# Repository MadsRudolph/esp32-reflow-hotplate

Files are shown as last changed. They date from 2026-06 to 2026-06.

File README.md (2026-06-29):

# ESP32 SMD Reflow Hotplate

A from-scratch SMD reflow hotplate built around an ESP32, a 24 V DC PTC heater plate,
and a custom CNC-milled single-sided control board. Designed to reflow small/medium
SMD boards (up to ~100 × 100 mm) using PID-controlled reflow profiles.

> **Status:** in design. See [`docs/`](docs/) for the design spec.

## Why DC PTC (not mains)

The heater runs on **24 V DC**, switched by a power MOSFET — no mains voltage anywhere
in the build. Safer to build, debug, and leave running than an SSR + AC element.

## System overview

| Subsystem | Choice |
|---|---|
| Controller | ESP32 DevKit module |
| Heater | 24 V DC PTC aluminium plate, ~300 W (~13 A) |
| Power switch | IRFS4710 N-MOSFET, 12 V gate drive |
| Temp sensing | K-type thermocouple + MAX31855 (SPI) |
| Logic supply | 24 V → 5 V via LM2576 switching regulator |
| Gate-drive supply | 24 V → 12 V via LM7812 |
| UI | SSD1306 OLED + rotary encoder + start/stop button |
| Control board | Single-sided, through-hole, CNC-milled (Roland SRM-20) |
| Enclosure | 3D-printed (offset electronics box + metal-standoff plate mount) |

Most passives, the MOSFET, regulators, connectors and the encoder come from the **DTU
component shop** (through-hole lab stock). The ESP32 DevKit, MAX31855 thermocouple
module, OLED, 24 V PSU and the PTC heater plate are external modules/hardware.

## Repository layout

```
docs/            design spec, BOM, sourcing notes
hardware/kicad/   KiCad 10 project (schematic + single-sided board)
hardware/3d/      Blender sources + exported STL/STEP for printing
firmware/         ESP32 reflow-control firmware
```

## Production

- **PCB:** CNC-milled on a Roland SRM-20 (FR-1), single-sided, top nets as wire bridges.
  Design rules match the DTU laser/mill process: 1.0 mm trace / 0.8 mm clearance.
- **Enclosure:** FDM 3D print. The hot-plate mount uses **metal standoffs** with an air
  gap from the plastic — the plate reaches ~250 °C and must never touch printed parts.

## Safety

Mains-free by design, but reflow temperatures are dangerous. Planned protections:
hardware gate pulldown (power-off = heater-off), an inline thermal cutoff fuse on the
heater, a fused 24 V input, and firmware thermal-runaway / over-temperature watchdogs.

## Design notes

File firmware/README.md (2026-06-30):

# ESP32 Reflow Hotplate — Firmware

Embedded C firmware for the ESP32 reflow hotplate, written on ESP-IDF via PlatformIO.
Implements PID-controlled reflow profiles, a local OLED+encoder UI, and a WiFi LAN
dashboard for live monitoring and profile management.

## Quick start

```bash
# Run host-side Unity unit tests (no hardware needed)
cd firmware
pio test -e native

# Build firmware for the ESP32 (requires ESP-IDF toolchain download on first run)
pio run -e esp32dev

# Flash and monitor
pio run -e esp32dev -t upload
pio device monitor -e esp32dev
```

## Pin map

| Signal | GPIO  | Notes |
|---|---|---|
| HEATER_PWM | 25 | Time-proportional slow PWM (~1–2 s window), fail-safe low |
| TC_SCK | 18 | MAX31855 SPI clock |
| TC_SO | 19 | MAX31855 SPI MISO (read-only; no MOSI) |
| TC_CS | 5 | MAX31855 chip select |
| OLED_SDA | 21 | SSD1306 I2C data |
| OLED_SCL | 22 | SSD1306 I2C clock |
| ENC_A | 32 | Rotary encoder channel A (PCNT) |
| ENC_B | 33 | Rotary encoder channel B (PCNT) |
| ENC_SW | 27 | Encoder push-switch (GPIO ISR) |
| BTN_START | 26 | Start/stop button |
| LED_STATUS | 4 | Status LED |
| FAN_PWM | 13 | 5 V cooling fan, split-range PID (low-side N-MOSFET); **not yet on the fabricated board — pending board revision** |

## Architecture

```
firmware/
  platformio.ini        env:esp32dev (espidf) + env:native (gcc + Unity)
  partitions.csv        app + nvs (profiles)
  src/
    core/   Pure C — no ESP-IDF deps; covered by native Unity tests
    hal/    ESP-IDF C drivers (bench-verified)
    ui/     OLED screens + encoder navigation
    net/    WiFi station + HTTP server + WebSocket dashboard
    app/main.c
  lib/core/             Pure-C library include path (for native env)
  test/test_smoke/      Smoke test: verifies toolchain and Unity work
```

## Safety

Hard over-temp cutoff at 260 °C (above SAC305 reflow peak, below damage threshold).
Runs are started and aborted **locally only** — the web dashboard is monitoring/profiles only.
WiFi credentials live in gitignored `src/net/wifi_config.h`.

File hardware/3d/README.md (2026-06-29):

# ESP32 Reflow Hotplate — 3D Enclosure

Parametric 3-part enclosure for the ESP32 reflow hotplate: a **plate frame** that
holds the ~250 °C heater plate on ceramic standoffs over an open air gap, an
**electronics box** that carries the 104×104 mm control board flat, and a **top
control panel** that closes the box and exposes the encoder, button, LED and OLED.

The whole model is parametric. Everything geometry-relevant lives in
[`params.py`](params.py); change a value there (e.g. the real plate dimensions)
and re-run [`build_all.py`](build_all.py) to regenerate all parts, the assembled
`enclosure.blend`, and the STL set.

---

## Files

| File | Role |
|---|---|
| `stl/plate_frame.stl`, `stl/box.stl`, `stl/panel.stl` | **Print these.** One STL per part. |
| `enclosure.blend` | Assembled scene (box at origin, panel on top, plate frame beside). Parametric source-of-truth render. |
| `params.py` | All dimensions/parameters. **Edit here**, then re-run. |
| `build_common.py` | Blender helpers (booleans, manifold check, STL export, verify). |
| `build_plate_frame.py`, `build_box.py`, `build_panel.py` | Per-part parametric builders (`build()` each). |
| `build_all.py` | Assembles all three, runs the box↔panel interference check, exports STL, saves `.blend`. |

**STEP export** is intentionally out of scope — Blender has no native STEP
exporter. If a STEP/CAD hand-off is needed, it is an optional FreeCAD follow-up
(import the STL or rebuild from `params.py`). The `.blend` + `build_*.py` are the
parametric source.

### Regenerating everything

In a running Blender (5.x) with the MCP/console:

```python
exec(open(r".../hardware/3d/build_all.py").read())
r = build_all()
print(r)
# all three parts -> manifold_ok True, fits_bed True
# interference.box_panel ~ 0  (box walls do NOT pass through the panel)
# 3 STL written to stl/, enclosure.blend saved
```

The build asserts each part is **manifold/watertight** (`nonmanifold == 0`) — a
non-watertight STL is never exported. The box↔panel interference is measured by a
temporary boolean INTERSECT whose volume must be ≈ 0 (only the rim/screw bosses
touch the panel underside; the walls must not intersect the panel body).

---

## Print settings

- **Material:** PETG (chosen for higher glass-transition temp and toughness near
  the warm enclosure; the plate itself is held off all plastic — see thermal note).
- **Walls / perimeters:** **≥ 3** (the screw bosses and standoff bosses rely on
  solid walls for thread/insert retention).
- **Infill:** **~25–40%** (gyroid or grid). Toward the higher end for the box if
  you want extra rigidity under the board + panel.
- **Layer height:** 0.2 mm is fine for all parts.
- **Supports:** enable for overhangs — specifically the **box terminal opening**
  (the rectangular J1/J2 cut-out in the −Y wall) and any **panel cut-out
  overhang**. The vent slots and bores are bridgeable but inspect them.
- **Orientation:** print box and plate frame floor-down (open side up); print the
  panel flat, control face up.

---

## Heat-set inserts

- **Type:** M3 brass heat-set inserts.
- **Boss bore:** **Ø 4.0 mm** (`insert_bore_d`), ~6 mm deep (`insert_bore_depth`)
  in each of the 4 box top-rim bosses.
- **Install:** push each insert in with a **soldering iron** set to ~200–230 °C —
  let the brass melt into the bore until flush with the boss top, then back the
  iron out straight so the insert stays square.

---

## Hardware BOM

| Qty | Item | Notes |
|-----|---|---|
| 4 | **M3 ceramic standoffs — FEMALE-THREADED** | **CRITICAL:** the plate-frame bosses are **blind** (solid foot below, no through-clearance for a bottom nut). The standoff must be **female-threaded** and **seat on the boss top**; the M3 screw threads **UP into the plate** from above. A plain spacer that needs a nut underneath the frame **will NOT fit.** |
| 4 | M3 steel screws (for the plate) | Thread up through the plate into the female ceramic standoffs. Length to suit plate thickness + a few mm of engagement. |
| 4 | M3 brass heat-set inserts | Pressed into the box top-rim bosses (Ø4.0 bore). |
| 4 | M3 screws (box↔panel) | Pass down through the panel clearance holes into the box-rim inserts. |
| 4 | Rubber feet | Stick-on, under the box (and/or plate frame). |
| 0 | Board screws | **None needed.** The control board has no mounting holes — it **rests on the box's 4 corner posts** and is captured from above by the top panel. |

---

## Assembly order

1. **Press the heat-set inserts** into the **box top-rim bosses** (4×, Ø4.0 bore)
   with a soldering iron; let them seat flush and square.
2. **Bolt the plate** to the **plate frame** on the **ceramic standoffs**: seat a
   female-threaded ceramic standoff on each boss, then run an M3 steel screw
   **up** from the standoff into the plate.
3. **Drop the control board** onto the box's **4 corner support posts** (no
   screws — it simply rests on the posts, lifted off the floor for the bottom
   lead tails).
4. **Wire the OLED module to J4** and seat it under the **panel's OLED window**.
5. **Screw the top control panel down** onto the box (4× M3 into the heat-set
   inserts). This captures the board and aligns the encoder / button / LED / OLED
   with their panel cut-outs.
6. **Stick the rubber feet** on the underside.
7. **Wire the power side** through the **terminal opening** in the box −Y wall:
   24 V-in (**J1**) and the heater output (**J2**), plus the **two thick power
   wire-bridges** and the **signal jumpers** per the PCB `MILL_NOTES`.

---

## Thermal safety

- The heater plate runs at roughly **~250 °C**. **Ceramic standoffs** plus the
  **22 mm air gap** (`standoff_h`) keep that plate off **all** plastic — nothing
  printed ever touches the hot plate.
- The **electronics box is physically offset** from the plate (separate part,
  placed beside it), keeping the control board out of the heat plume.
- This is a conservative starting point. **Re-verify** the standoff height / air
  gap and the box offset **once the real plate's sustained surface temperature is
  known** — if the production plate runs hotter or the plume is wider than
  assumed, increase `standoff_h` (and/or the box offset) in `params.py` and
  re-run `build_all.py`.

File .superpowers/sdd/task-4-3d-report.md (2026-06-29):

# Task 4 — Top control panel (`build_panel.py`) report

## Affine (board frame → panel frame)
The board is centred in the box, so the board centre `(pcb_x/2, pcb_y/2)` maps to
the panel centre `(0,0)`. placement.json positions are in board frame (origin at
board lower-left). The map is a pure translation:

```
panel_x = board_x - pcb_x/2   (= board_x - 52.0)
panel_y = board_y - pcb_y/2   (= board_y - 52.0)
```

Checks: SW1 (25.6,11.1)→(-26.4,-40.9); SW2 (41.9,7.8)→(-10.1,-44.2);
D1 (52.7,7.2)→(0.7,-44.8); J4 (5.8,9.6)→(-46.2,-42.4).

## What was built
PETG plate `box_x × box_y × panel_t` = 113×113×3, top face up (z=0..3). One
manifold object `panel`. Cuts (all booleaned through):
- Encoder shaft Ø7.5 (encoder_shaft_d) at SW1
- Push-button Ø12.5 (button_d) at SW2
- LED Ø5.5 (led_d) at D1
- OLED window 26×15 (oled_win_x × oled_win_y, X×Y) at J4
- Vent slots (4 × 2.5×18, pitch 6) over the regulator zone: centred at the
  midpoint of U2/U3 mapped through the affine (panel x≈-1.55, y≈-21.7), i.e. the
  power corner (placement.json `_doc`: lower-left) regulator/MOSFET band.
- 4 × Ø3.4 M3 clearance holes at `top_insert_centers()` = (±52.5, ±52.5).

## Verification (real Blender output)
```
verify = {"nonmanifold": 0, "bbox": (113, 113, 3),
          "manifold_ok": True, "fits_bed": True}
cut_centers = {"SW1": (-26.4,-40.9), "SW2": (-10.1,-44.2),
               "D1": (0.7,-44.8), "J4": (-46.2,-42.4)}
MATES box rim = True
hole_centers       = [(-52.5,-52.5),(-52.5,52.5),(52.5,-52.5),(52.5,52.5)]
top_insert_centers = [(-52.5,-52.5),(-52.5,52.5),(52.5,-52.5),(52.5,52.5)]
```
Single watertight solid. STL written: `hardware/3d/stl/panel.stl`.

## Files changed
- `hardware/3d/build_panel.py` (new)
- `hardware/3d/stl/panel.stl` (new)

## Concerns
- OLED window orientation assumed `oled_win_x` along panel X, `oled_win_y` along
  panel Y (J4 rotation in placement.json is 0). If the physical OLED module is
  rotated, the window may need swapping — low risk given the 0° placement.
- Vent slots are a small decorative/airflow row over the regulator zone; exact
  count/pitch chosen for manifold cleanliness, not validated against a thermal
  model.

## Review fix (vents from JSON + OLED rot)

### What changed
1. **Vent anchors from placement.json** (`build_panel.py` lines ~111-125): removed
   the two hardcoded board-x literals `42.5` (U2) and `58.4` (U3). The build
   function now reads `placement.json` keys `U2` and `U3` at runtime using
   `_pl.get("U2", [42.5, 30.3, 0])` / `_pl.get("U3", [58.4, 30.3, 0])`, maps
   them through the existing `_affine()` call, and computes `vent_cx`/`vent_cy`
   from those results. Fallback defaults (the original literals) are used only if
   a key is absent — no crash.

2. **J4 rotation assert** (`build_panel.py` before the OLED boolean): added
   `assert pl_j4_rot == 0` with a message explaining how to handle 90°/270°
   rotation (swap `oled_win_x`/`oled_win_y`). This will surface immediately if
   the board is respun with a rotated OLED header.

### JSON-derived vent anchors (from real Blender run)
| Component | Board frame (mm) | Panel frame (mm) |
|---|---|---|
| U2 | [42.5, 30.3] | (-9.5, -21.7) |
| U3 | [58.4, 30.3] | (6.4, -21.7) |
| vent_cx | — | -1.55 |
| vent_cy | — | -21.7 |

### Verification output (real Blender output)
```
verify = {'nonmanifold': 0, 'bbox': (113.0, 113.0, 3.0), 'manifold_ok': True, 'fits_bed': True}
cut_centers = {'SW1': (-26.4, -40.9), 'SW2': (-10.1, -44.2), 'D1': (0.7, -44.8), 'J4': (-46.2, -42.4)}
MATES = True
U2 board=[42.5, 30.3] -> panel=(-9.5, -21.7)
U3 board=[58.4, 30.3] -> panel=(6.4, -21.7)
vent_cx=-1.55, vent_cy=-21.7
STL exported OK
```
Still manifold; cut_centers unchanged; MATES True; STL re-exported.

## OLED window overhang fix

### Root cause
The OLED window (J4) was centred at panel (−46.2, −42.4), derived from the J4
board footprint via the affine transform. With `oled_win_x = 26 mm`, the window's
left edge fell at `−46.2 − 13.0 = −59.2 mm`, overhanging the panel half-width of
56.5 mm by **2.7 mm** — an open-sided notch instead of an enclosed window.

### Why the fix is a free design choice
The SSD1306 OLED module connects to J4 via a short 4-wire cable (JST), not by
sitting directly above the connector. The panel window position is therefore
**independent of J4's board coordinate** and can go anywhere on the panel
consistent with the geometry constraints.

### New OLED position
`_OLED_PANEL_X = −25.0 mm`, `_OLED_PANEL_Y = 20.0 mm` — upper-left quadrant of
the panel, clear of the SW1/SW2/D1 control row (which sits at y ≈ −41 to −45 mm).

Window edge coordinates (26×15 mm window, half-extents 13 and 7.5 mm):

| Edge | Value (mm) | Panel limit (mm) | Margin (mm) |
|---|---|---|---|
| Left | −38.0 | −53.5 | +15.5 |
| Right  | −12.0 | +53.5 | +65.5 |
| Bottom | +12.5 | −53.5 | +66.0 |
| Top | +27.5 | +53.5 | +26.0 |

All four edges are well within ±53.5 mm. Nearest screw hole is at (−52.5, 52.5)
Ø3.4 mm; gap from screw edge to window edge ≥ 12.8 mm (requirement: ≥ 2 mm).

### The guard: `_assert_inside_outline()`
Added to `build_panel.py`. Checks every cut before the booleans run:
- **Control holes** (SW1 encoder, SW2 button, D1 LED): centre ± radius within
  ±(box/2 − 3 mm) = ±53.5 mm.
- **OLED window**: centre ± half-extent within ±53.5 mm.
- **Screw holes**: centre ± radius within ±(box/2 − 1 mm) = ±55.5 mm (corner
  holes are by design near panel corners within the wall zone; 1 mm physical
  margin is appropriate for them).

Called in `build()` immediately after `cut_centers()`. Raises `AssertionError`
with an explicit message identifying the offending cut and edge coordinate.

### Guard fires on the bad position
Temporarily overriding the OLED center to the original bad position (−46.2, −42.4)
triggers:
```
AssertionError: _assert_inside_outline: OLED window left edge -59.200 < -53.500
```
The guard has teeth — it catches the open-sided-notch class of bug that the
manifold check misses (a manifold solid can still have open-sided slots if the
panel outline itself is intact but a cut overhangs an edge).

### Verification output (real Blender run after fix)
```
verify = {'nonmanifold': 0, 'bbox': (113, 113, 3), 'manifold_ok': True, 'fits_bed': True}
cut_centers = {'SW1': (-26.4, -40.9), 'SW2': (-10.1, -44.2), 'D1': (0.7, -44.8), 'J4': (-25.0, 20.0)}
MATES = True
OLED edges: left=-38.0, right=-12.0, bottom=12.5, top=27.5  (all within ±53.5)
_assert_inside_outline: PASSED on new position
_assert_inside_outline: FIRES on bad position (-46.2, -42.4) with message above
STL re-exported: hardware/3d/stl/panel.stl
```
SW1/SW2/D1 centres unchanged. MATES True. Manifold. OLED fully enclosed.

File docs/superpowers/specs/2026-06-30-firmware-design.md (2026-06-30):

# ESP32 Reflow Hotplate — Firmware Design Spec

**Date:** 2026-06-30
**Status:** Approved (brainstorming complete; ready for implementation planning)
**Parent project:** ESP32 SMD Reflow Hotplate (see `2026-06-29-esp32-reflow-hotplate-design.md` §6)

## 1. Goal

Firmware for the ESP32 reflow hotplate: read the plate temperature, run a PID-controlled
reflow profile to drive the 13 A heater safely, present a local OLED + encoder UI, and
serve a WiFi web dashboard on the LAN for live monitoring and profile management.
Written in **embedded C on ESP-IDF** (PlatformIO), with the safety-critical control logic
isolated as pure C and unit-tested natively.

### Non-goals (YAGNI)
- No remote start/abort of reflow runs — runs are started/aborted **locally only** (a 13 A
  heater must not be started unattended over the network).
- No cloud/internet dependency — the dashboard is served by the device on the LAN.
- No OTA firmware update in v1.
- No multi-plate / multi-zone control.

## 2. Key decisions (from brainstorming)

| Decision | Choice | Reason |
|---|---|---|
| Language / framework | **Embedded C on ESP-IDF** (PlatformIO `framework = espidf`) | Pure C, no C++/Arduino; native C driver APIs + FreeRTOS |
| Control loop | **PID**, position form, anti-windup, derivative-on-measurement; fixed conservative default gains | Reliable reflow tracking; tune once per plate |
| Heater output | **Time-proportional control** (slow ~1–2 s PWM window on GPIO25), fail-safe low | Standard for thermal/heater control |
| Cooling / fan | **5 V fan on GPIO13**, driven as the cooling half of a **bipolar split-range PID** (heater vs fan, deadband) | Active cooling on the down-ramp → more accurate curves; needs a board revision |
| Testability | `core/` is pure C (no ESP-IDF deps) → **PlatformIO `native` Unity tests**; HAL bench-verified | Fast TDD for the safety-critical logic |
| Profiles | **Editable, persisted to NVS** (`nvs_flash`); seeded with leaded Sn63/Pb37 + lead-free SAC305 | Tweak without reflash; managed from OLED and web |
| Local UI | SSD1306 OLED + rotary encoder + start/stop button | Standalone operation |
| Network | **WiFi station + `esp_http_server`**; embedded SPA dashboard; WebSocket live telemetry; REST profile CRUD | LAN monitoring + profile management |
| Dashboard scope | **Monitor + manage profiles**; runs start/abort LOCAL only | Fire-safety for a 13 A heater |
| Safety ceiling | Hard over-temp cutoff **260 °C** | Above SAC305 peak, below damage |
| WiFi credentials | Gitignored `wifi_config.h` (or NVS) | Simple; never commit creds |

## 3. Architecture (layered for isolation + testability)

```
firmware/                         PlatformIO project (framework = espidf)
  platformio.ini                  env:esp32dev (espidf) + env:native (gcc + Unity)
  partitions.csv                  app + nvs (profiles)
  src/
    core/      PURE C — NO ESP-IDF/Arduino deps → native Unity tests
      pid.c/.h        position PID, anti-windup clamp, derivative-on-measurement (BIPOLAR output)
      actuator.c/.h   split-range: bipolar effort → (heater_duty, fan_duty) with a deadband
      profile.c/.h    profile model (stages) + setpoint-vs-time interpolation + validation
      reflow.c/.h     run state machine (idle→preheat→soak→reflow→cool→done / fault)
      safety.c/.h     watchdog: pure verdict from (temp, heater_duty, dt, flags)
      settings.c/.h   profile store; storage behind a struct-of-fn-pointers (fake in tests)
    hal/       ESP-IDF C drivers (bench-verified, not native-tested)
      tc_max31855.c   driver/spi_master: read 32-bit word, parse temp + fault bits
      oled_ssd1306.c  driver/i2c_master: minimal text/line/bar driver
      heater.c        time-proportional slow-PWM on GPIO25; fail-safe low
      fan.c           5 V cooling fan PWM (LEDC) on GPIO13; off on init/abort/fault
      encoder.c       PCNT peripheral (A/B) + GPIO ISR for switch
      button.c, led.c GPIO
    ui/ui.c           OLED screens + encoder navigation (depends on core + hal)
    net/       WiFi + web (independent of the control loop)
      wifi.c          esp_wifi station; creds from gitignored wifi_config.h
      httpd.c         esp_http_server: serves SPA + REST + WebSocket
      api.c           endpoints; reads run snapshot, writes profiles via settings.c
      www/            dashboard SPA (HTML/CSS/JS), embedded into flash (EMBED_FILES)
    app/main.c        app_main: nvs init, HAL init, wifi/httpd start, control FreeRTOS task
  test/native/        Unity tests for core/*
  README.md           pinout, build/flash, bench-verification steps
```

### 3.1 Pin map (from `hardware/kicad/net_contract.json`)
`HEATER_PWM=GPIO25, TC_SCK=GPIO18, TC_SO=GPIO19, TC_CS=GPIO5, OLED_SDA=GPIO21,
OLED_SCL=GPIO22, ENC_A=GPIO32, ENC_B=GPIO33, ENC_SW=GPIO27, BTN_START=GPIO26,
LED_STATUS=GPIO4, FAN_PWM=GPIO13`. SPI is read-only (no MOSI); MAX31855 is the only SPI
device. **FAN_PWM (GPIO13)** drives a 5 V cooling fan — added 2026-06-30; it is NOT on the
fabricated board yet and needs a board revision (see §12).

## 4. Control core (`core/`)

- **`pid`** — position-form PID; **bipolar output −100…+100 %** (positive = heat demand,
  negative = cool demand). Anti-windup (conditional integration on either rail); derivative
  on the measurement (not the error) to avoid a setpoint kick at stage boundaries; NaN/Inf
  output → fail-safe minimum. Conservative default `Kp/Ki/Kd` in config; documented tuning.
- **`actuator` (split-range)** — maps the bipolar PID effort to two non-overlapping outputs
  with a deadband: `effort > +deadband` → `heater_duty = effort, fan_duty = 0`;
  `effort < −deadband` → `fan_duty = |effort|, heater_duty = 0`; inside the deadband both
  off. **Heating and cooling are never commanded at once.** Pure function, fully unit-tested.
- **`profile`** — a profile is an ordered list of stages `{name, target_c, duration_s}`
  for preheat → soak → reflow(peak) → cool. `profile_setpoint(profile, elapsed_s)` returns
  the interpolated target. `profile_validate()` enforces: stage count/limits, monotonic
  time, each `target_c ≤ SAFETY_CEILING`, sane durations — used by both OLED edits and
  web uploads.
- **`reflow`** — the run state machine: `IDLE → PREHEAT → SOAK → REFLOW → COOL → DONE`,
  plus `FAULT`. Advances stages by the profile; computes the live setpoint; consumes the
  `safety` verdict to abort. Publishes a run snapshot.
- **`safety`** — pure function evaluated every tick; forces heater + fan OFF + `FAULT` on:
  over-temp (`≥ 260 °C`), thermal runaway (**heater_duty** high but temp not rising ≥ ~2 °C /
  20 s — evaluated on heater duty only, so active fan cooling never trips it), thermocouple
  fault (open/short/NaN/out-of-band), sensor stall (no fresh reading in timeout). Faults
  latch until acknowledged.
- **`settings`** — profile CRUD over an injected `storage_if` (struct of read/write fn
  pointers). On-device it binds to NVS; in native tests, to an in-memory fake. Seeds the
  two default profiles on first boot.

## 5. HAL (`hal/`, ESP-IDF C)
Thin wrappers, no business logic: `tc_max31855` (SPI word → °C + fault), `oled_ssd1306`
(I²C text/line/bar), `heater` (time-proportional slow-PWM, fail-safe low on init/abort),
`fan` (5 V cooling-fan PWM via LEDC on GPIO13, off on init/abort/fault), `encoder` (PCNT
quadrature + GPIO ISR switch), `button`, `led`. Verified on the bench; the steps are
documented in `firmware/README.md`.

## 6. Local UI (`ui/`)
```
IDLE/SELECT → rotate: pick profile → press: MENU {RUN, EDIT}
EDIT  → pick stage field (temp/time), adjust, save → NVS
RUN   → live: target vs actual °C, stage, elapsed, duty bar  (button aborts)
DONE/COOLDOWN → "remove board, cooling" until cool → IDLE
FAULT → reason; button acknowledges → IDLE
```
Encoder rotate = navigate/adjust, encoder press = select, dedicated button = start/abort.

## 7. Network dashboard (`net/`)
- **`wifi`** — station mode; joins the LAN using creds from a gitignored `wifi_config.h`
  (SSID/pass) — never committed. WiFi/web failure must NOT affect the control loop.
- **`httpd`/`api`** — `esp_http_server`:
  - `GET /` → embedded SPA (HTML/CSS/JS in flash; no internet dependency).
  - `GET /ws` → WebSocket pushing live telemetry ~2–4×/s: `t, target, actual, duty, stage,
    state, fault`.
  - `GET /api/status` → snapshot (first paint / non-WS clients).
  - `GET /api/profiles`, `GET /api/profiles/{id}` → read.
  - `POST /api/profiles`, `PUT /{id}`, `DELETE /{id}` → create/edit/upload/delete a profile
    (JSON), `profile_validate()`d, then persisted to NVS via `settings`.
- **Dashboard SPA** — live temperature chart (target vs actual) + stage/duty/state/fault
  tiles; a profile manager (list → edit form → save/upload/delete). Self-contained.
- **Concurrency / safety boundary** — the control FreeRTOS task owns the heater and run
  state and publishes a snapshot (mutex/atomic). The httpd task only *reads* the snapshot
  and *enqueues validated profile writes*; it can never command the heater or start a run.

## 8. Telemetry
During a run, also stream one CSV line per tick over USB serial (`t,target,actual,duty,
stage`) for plotting and PID tuning.

## 9. Concurrency model (FreeRTOS)
- **Control task** (fixed tick, e.g. 250 ms, high priority): TC read → `safety` →
  `pid` (bipolar) → `actuator` (split-range) → `heater` + `fan` duties → publish snapshot →
  `ui` update + serial CSV. Owns all heater AND fan control.
- **httpd task** (esp_http_server): serves dashboard, reads the published snapshot, pushes
  WS telemetry, handles profile CRUD (enqueues writes consumed by the control/settings side).
- **wifi** events handled async. The control + safety loop is independent of WiFi/web state.

## 10. Testing (PlatformIO `native` env, Unity)
- `pid`: step response, anti-windup saturation, no derivative kick at setpoint change.
- `actuator`: positive effort → heater only; negative → fan only; deadband → both off;
  never heater+fan simultaneously; clamps to valid duty ranges.
- `profile`: interpolation across stage boundaries; `profile_validate` accepts good /
  rejects bad (non-monotonic, over-ceiling, zero-duration); defaults correct.
- `reflow`: full state-machine path + abort + fault transitions.
- `safety`: each trip fires and forces heater off; **fakes feed adversarial inputs** —
  the regression net for a 13 A heater.
- `settings`: CRUD + persist + reload through the in-memory `storage_if` fake.
HAL, UI, and net are bench/integration-verified (documented in README), not native-tested.

## 11. Repository layout
```
firmware/   the PlatformIO ESP-IDF project above (src/, test/native/, platformio.ini, README.md)
```

## 12. Risks & open items
- **PID tuning:** ship conservative gains; first-run tuning expected (serial CSV + dashboard
  chart aid this). Re-tune for the real plate's thermal mass.
- **OLED/encoder C drivers:** minimal hand-rolled drivers (no Adafruit) — budget bench time.
- **WiFi creds:** gitignored `wifi_config.h`; document the template. Provisioning portal is
  a later option.
- **Heater fail-safe:** `heater` must drive GPIO25 low on init, abort, fault, and task crash;
  this complements the hardware boot-safe gate. Covered explicitly in tests/bench checks.
- **Fan board revision (hardware):** the 5 V cooling fan on `FAN_PWM`=GPIO13 is NOT on the
  fabricated board — it needs a board revision: a logic-level N-MOSFET (2N7000/BS170) low-side
  switching the fan off `+5V`, a flyback diode, and a 2-pin fan connector (the `FANDRV`
  sub-circuit in `net_contract.json`). Folds into the next board spin (production files already
  stale from the PCB re-placement). The firmware `fan` HAL must default the GPIO low/off.
- **Flash size for the embedded SPA:** keep the dashboard self-contained and small; verify it
  fits the app partition.

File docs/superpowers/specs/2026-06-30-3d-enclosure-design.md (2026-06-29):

# ESP32 Reflow Hotplate — 3D Enclosure Design Spec

**Date:** 2026-06-30
**Status:** Approved (brainstorming complete; ready for implementation planning)
**Parent project:** ESP32 SMD Reflow Hotplate (see `2026-06-29-esp32-reflow-hotplate-design.md` §7)

## 1. Goal

Design the 3D-printable enclosure for the reflow hotplate: hold the ~250 °C heater plate
safely above the electronics, house the CNC-milled control board, and present the OLED +
encoder + button + LED on a front panel. Deliverables: parametric Blender source + exported
STL (print) and STEP (CAD interchange) for each part.

### Non-goals (YAGNI)
- No active cooling (no fan) — passive vents only.
- No latching/hinged lid — the lid is screwed.
- No enclosure for the 24 V PSU (external brick stays separate).

## 2. Key decisions (from brainstorming)

| Decision | Choice | Reason |
|---|---|---|
| Heater plate | Parametric around 100×100 mm aluminium PTC, 4× corner M3 holes | No specific plate yet; adapt later by changing variables |
| Layout | Electronics box **offset to the side** of the plate | Keeps all plastic out of the rising heat plume — safest |
| Thermal isolation | Plate on **ceramic standoffs** (~20–25 mm) + open air gap | Ceramic conducts little heat → PETG base stays well below its ~80 °C Tg |
| Fastening | **M3 brass heat-set inserts** in PETG for the box↔top-panel joint; plate uses steel M3 screws through **female-threaded** ceramic standoffs; the control board **rests on corner posts** (it has no mounting holes) | Durable, re-openable threads; the board needs no holes |
| Parts | **3 printed: plate frame, electronics box, top control panel** | The board's controls point up, so one TOP panel both closes the box and carries the cut-outs (it is also the lid) |
| Material | PETG (base/box); hot zone is all metal/ceramic | Better heat tolerance than PLA; nothing plastic touches the plate |
| Modeling | Blender (MCP), parametric variables | **STL + the parametric `.blend`/`.py`** (Blender has no native STEP export; STEP is an optional FreeCAD follow-up) |

> **Design correction (2026-06-30, mid-build):** the original 4-part plan (vertical front panel + separate lid) was geometrically wrong — the 104×104 board is larger than the first box envelope, has no mounting holes, and its through-hole controls (SW1/SW2/D1) point *up*, so they must come through a panel parallel and above the board. Corrected to the 3-part design below.

## 3. Architecture (3 printed parts + hardware)

### 3.1 Plate frame
PETG base/ring that the heater plate bolts onto via **4 female-threaded ceramic standoffs** (the
standoff seats on the frame's blind boss; a steel M3 screw threads UP through the standoff into
the plate's corner hole — NOT down through the frame). The standoffs raise the plate ~22 mm with
an **open air gap** beneath, and the ceramic is the only thermal path to the printed part —
breaking conduction. Footprint and hole pattern are parametric to the plate. A routed channel
carries the plate's heater wires toward the electronics side. Feet under the corners.

### 3.2 Electronics box
Sits **beside** the plate frame, out of the heat plume, sized (~113×113 mm) to hold the **104×104
control board flat**. The board **rests on 4 corner support posts** (lifted off the floor for the
bottom lead tails) — it has no mounting holes, so it is captured from above by the top panel, not
bolted. Features:
- Vent slots above the LM2575 / LM7812 regulators and the Q1 (IRFS4710) TO-220 heatsink.
- Side openings for the 24 V-in (J1) and heater-out (J2) screw terminals.
- **Heat-set inserts on the top rim** to receive the top control panel.

### 3.3 Top control panel (also the lid)
A PETG plate that **closes the box top** and carries the controls — the user looks down on it.
Cut-outs **aligned to the control board's on-board component positions** (from
`hardware/kicad/placement.json`, board centred under the panel): the rotary encoder (SW1) shaft,
the start button (SW2), the status LED (D1), and an **OLED window** for the J4-connected SSD1306
module. Vent slots over the heat-generating zone. Bolts down into the box top-rim heat-set inserts
with M3 screws.

### 3.4 Hardware (bring-your-own)
- Plate: 4× **female-threaded** ceramic standoffs + 4× steel M3 screws.
- Box↔panel: M3 brass heat-set inserts + M3 screws.
- 4× rubber feet. (The control board needs no screws — it rests on the box posts.)

## 4. Thermal safety rationale
The ~250 °C plate never contacts printed plastic: it stands on ceramic over an air gap, and the
electronics box is laterally offset from the plume. PETG (Tg ~80 °C) is used for structure; the
ceramic standoffs + air gap keep the frame's screw bosses far below softening even on sustained
runs. (The plate-mount geometry should be sanity-checked against the real plate's wattage during
implementation.)

## 5. Parametric variables (Blender)
Single source of truth so the model adapts to the real plate and board:
- `plate_x`, `plate_y`, `plate_thickness` (default 100, 100, ~5 mm)
- `plate_hole_inset`, `plate_hole_dia` (corner M3 pattern)
- `standoff_height` (air gap, default ~22 mm), `standoff_dia`
- `insert_dia_m3`, `insert_depth` (heat-set boss geometry)
- `panel_cutouts`: SW1/SW2/D1/OLED positions + sizes, driven by the board's
  `placement.json` coordinates
- `wall_thickness`, `bed_max` (220 mm) for part-splitting checks

## 6. Repository layout
```
hardware/3d/
  enclosure.blend           Blender source (parametric)
  stl/                      exported STL per part (print)
  step/                     exported STEP per part (CAD)
  README.md                 print settings, insert sizes, assembly + hardware BOM
```

## 7. Verification (the 3D equivalent of tests)
- Each part exports a manifold (watertight) STL — checked in Blender (no non-manifold edges / holes).
- Fit checks against parameters: plate-hole pattern matches `plate_*`; panel cutout coords match
  `placement.json`; heat-set boss bores match the chosen insert (e.g. M3 → ~4.0 mm).
- Every part's bounding box ≤ 220×220 mm (bed); flag any that needs splitting.
- Wall thickness ≥ a printable minimum; standoff/air-gap height ≥ the thermal-safety value.
- Assembly dry-run in Blender: parts mate without interference (box ↔ panel ↔ lid; plate frame
  standoff spacing).

## 8. Risks & open items
- **Plate spec (still the key input):** exact plate dimensions/holes/thickness and the real wire
  exit must be confirmed before the final print; the parametric model makes this a variable change.
- **Standoff height vs. heat:** ~22 mm air gap assumed safe; re-check once the plate's sustained
  surface/edge temperature is known.
- **Panel ↔ board alignment:** cut-out positions depend on `placement.json`; if the board is ever
  re-placed, regenerate the panel.
- **Insert pull-out:** boss walls must be thick enough for M3 heat-set inserts under panel/lid load.

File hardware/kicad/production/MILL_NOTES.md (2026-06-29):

# SRM-20 Milling Notes — ESP32 Reflow Hotplate

Board: `reflow.kicad_pcb` — single-sided (B.Cu traces), 86 F.Cu top jumpers (wire bridges), 3 high-current pours (+24V, HEATER_RET, GND).

---

## Production files

| File | Purpose |
|---|---|
| `reflow_mill_bcu.svg` | **Mirrored** B.Cu — feed to mods CE or gerber2rml for trace job |
| `reflow.dxf` | B.Cu + Edge.Cuts (DXF) |
| `reflow_top_cu.dxf` | F.Cu + Edge.Cuts — wire-bridge wiring guide |
| `reflow-F_Cu.dxf` | F.Cu standalone DXF |
| `reflow_silk_top.dxf` | F.Silkscreen (optional engraving) |
| `gerbers/reflow-B_Cu.gbl` | B.Cu Gerber |
| `gerbers/reflow-Edge_Cuts.gm1` | Board outline Gerber |
| `gerbers/reflow.drl` | Excellon drill file |
| `gerbers/reflow-*.g*` | Full Gerber set (masks, fab, silk) |

---

## Three SRM-20 jobs

### Job 1 — Traces (B.Cu)

- **Source file:** `reflow_mill_bcu.svg` (already mirrored — do NOT mirror again in mods)
- **Bit:** 1/64" (0.4 mm) flat end mill
- **mods CE settings:** `mill traces`, depth **0.10–0.15 mm**, offsets **2** (channels are 0.8 mm wide — 2 offsets clears them exactly; `-1` = clear all = very slow, use only if isolation fails)
- **Feed rate:** 4 mm/s (SRM-20 spindle tops at 7000 rpm — do not raise feed, 1/64" bits snap)
- **Travel/jog height:** 2–5 mm (don't set 12+ mm, just slow)

> **Wide-pour caveat:** the +24V, HEATER_RET, and GND pours have 0.8 mm clearance channels around them. The 1/64" bit just fits 2 offsets. If any pour boundary fails to isolate after milling, re-run that region with `-1` offsets (raster-clear) or touch up manually with a multimeter to verify.

### Job 2 — Holes

- **Source:** `gerbers/reflow.drl` (Excellon) or render `gerbers/reflow-Edge_Cuts.gm1` + `reflow.drl` to PNG in a Gerber viewer and mirror in GIMP — OR drill by hand after laser flow.
- **Bit:** 1/32" (0.8 mm)
- **mods CE settings:** `mill outline`, depth **0.6 mm/pass**, total **1.8 mm** (through 1.6 mm board)
- Note: **all three jobs are viewed from the underside** (copper face up in machine). Mirroring already done in SVG for job 1; apply same mirror to hole and outline PNGs if rendering.

### Job 3 — Board cutout (Edge.Cuts)

- **Source:** `gerbers/reflow-Edge_Cuts.gm1` (mirror as above)
- **Bit:** 1/32" (0.8 mm)
- **Settings:** same as holes — depth 0.6 mm/pass, total 1.8 mm

---

## Machine setup

### Material

Use **FR-1 (phenolic)** if available. FR-4 can be milled but glass-fibre dust wears 1/64" bits within 1–2 boards and is a health hazard — use a vacuum and dust mask. Ask the fablab shop for FR-1.

### Board preparation

- Stock size: any piece ≥ 110 × 110 mm (board is ~109 × 109 mm). SRM-20 work area is 203 × 152 mm.
- Mount on a sacrificial MDF plate with **double-sided tape over the entire back surface** — a 0.1 mm bump shows in milling depth. Press the board completely flat.

### Origin / Z-zero procedure

1. Jog the spindle to the **lower-left corner** of the board → `Set Origin X/Y` in VPanel.
2. **Z-zero:** lower the bit to just above the copper surface, loosen the collet set-screw so the bit drops and rests on the copper, re-tighten → `Set Origin Z`. (Classic SRM-20 trick — gives Z-zero exactly at the copper surface.)
3. Run **Job 1** (1/64" traces).
4. **Bit change:** swap to 1/32". Re-run Z-zero only (XY origin is preserved). Run **Jobs 2+3** (holes + cutout).

### Post-mill check

Multimeter **continuity check** of all adjacent trace pairs after milling. Pay particular attention to:
- **SW1 encoder** — ~0.5 mm intrinsic pad gap (near 0.4 mm bit limit)
- **D1 LED** — ~0.74 mm pad gap (near limit)

If any pair short, clean the channel with a sharp tool or fine sandpaper, then re-test.

---

## Hand-finish items — CRITICAL

The SRM-20 mill produces the B.Cu traces only. This board is **not complete from the mill alone**. The following must be done by hand:

### A) Top-side signal wire bridges (~86 jumpers)

Use `reflow_top_cu.dxf` (or `reflow-F_Cu.dxf`) as the wiring guide. Solder **thin insulated wire** (e.g. 28–30 AWG kynar wire-wrap or similar) for each F.Cu segment shown. Work systematically — mark each completed bridge.

### B) Two high-current wire bridges — USE THICK WIRE (18–20 AWG solid)

These two nets carry ~13 A heater current and are geometrically un-routable on single-sided B.Cu in this layout. The B.Cu corridors are too narrow to carry 13 A — **top-side wire bridges are required and must be short and thick.**

| Net | From | To | Notes |
|---|---|---|---|
| `+24V` | C3 pin 1 | F1 pin 2 | Only ~1 mm B.Cu corridor exists — bridge mandatory |
| `HEATER_RET` | D4 pin 1 | J2 pin 2 | ~2 mm clearance corridor — bridge mandatory |

Use 18–20 AWG solid tinned copper wire. Keep bridges as short as possible. Secure with a dab of hot glue or epoxy after soldering.

### C) Tight-isolation check

After milling, verify isolation with a multimeter on:
- **SW1 encoder** (~0.5 mm pad gap) — pads must not short
- **D1 LED** (~0.74 mm pad gap) — pads must not short

Do a manual touch-up with a sharp scribe or fine rotary tool if needed.

### D) Silkscreen / cosmetic (optional)

F.Silkscreen (`reflow_silk_top.dxf`) can be engraved separately on a laser engraver for reference designators, or skipped entirely. The two no-net laser-fill zone warnings and Q2/Q3 silk-overlap DRC items are cosmetic only — no connectivity impact.

---

## Toolchain reference

- **mods CE:** https://modsproject.org — browser-based, Fab Academy standard. `programs → open program → machines → Roland → SRM-20 mill → mill 2D PCB`
- **gerber2rml alternative:** `tools/srm-cam` — generates `.rml` or `.nc` directly from Gerbers, skips the PNG/mods step. Select `Roland SRM-20 (G-code)` in GUI or pass `--gcode` on CLI. Validated 2026-06-22 at 0.15 mm isolation with a sharp, short bit.
- **VPanel for SRM-20** (on the machine's PC): `Cut → Add → Output`

> Validated isolation depth: **0.15 mm** with a sharp, short 1/64" bit. A dull or long bit burns the copper and cuts too deep — inspect the bit before each job.

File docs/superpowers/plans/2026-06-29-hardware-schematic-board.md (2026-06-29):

# Reflow Hotplate — Hardware (Schematic + Board) Implementation Plan

> **For agentic workers:** REQUIRED SUB-SKILL: Use superpowers:subagent-driven-development (recommended) or superpowers:executing-plans to implement this plan task-by-task. Steps use checkbox (`- [ ]`) syntax for tracking.

**Goal:** Produce a KiCad 10 schematic and a single-sided, through-hole, CNC-millable control board for the ESP32 reflow hotplate, with production files ready for the Roland SRM-20.

**Architecture:** One control board (spec Approach A). A 24 V input feeds an LM2576 switcher (5 V logic) and an LM7812 (12 V gate-drive rail). An IRFS4710 low-side MOSFET switches the 13 A heater through wide copper pours in an isolated "power corner"; a two-stage non-inverting BS170 level shifter drives its gate boot-safe. An ESP32 DevKit reads a MAX31855 thermocouple over SPI and drives an SSD1306 OLED + rotary encoder + start button. Built with a Python schematic-generator script (the project's established `build_v1_schematic.py` pattern), then routed/exported via the `kicad-laser-pcb` skill and milled per `SRM20_MILL.md`.

**Tech Stack:** KiCad 10.0 (CLI + s-expression `.kicad_sch`/`.kicad_pcb`), Python 3.13 + `sexpdata`, the `kicad-laser-pcb` skill scripts (`pcb_build.py`, `route_board.ps1`, `export_production.ps1`, `bom_to_md.py`), Freerouting (Java 21).

## Global Constraints

- **KiCad version:** KiCad **10.0** only. CLI at `C:\Program Files\KiCad\10.0\bin\kicad-cli.exe`; pcbnew Python at `C:\Program Files\KiCad\10.0\bin\python.exe`. The 9.0 CLI cannot read these files. Pass `-KicadBin "C:\Program Files\KiCad\10.0\bin"` to `route_board.ps1` / `export_production.ps1`, and set `KICAD_LASER_EXTRA_LIBS` to this repo's `hardware/kicad/lib` when running `pcb_build.py`.
- **Design rules:** track **1.0 mm**, clearance **0.8 mm**, single-sided (B.Cu copper), **through-hole only**, top-layer nets realised as wire bridges (`*_top_cu.dxf`). Do not lower these — they come from the mill/laser process.
- **Footprint libs (vendored into repo, project-local `fp-lib-table` with `${KIPRJMOD}` relative paths):** `energy_system.pretty` (TO-220 `_LaserPads_GDS` variant for the MOSFET, plain `_LaserPads` for regulators) and `TerminalBlock.pretty` (bornier P5.08 mm). Source of truth: the DTU Electrical Energy Systems repo `hardware/kicad/lib/`.
- **Sourcing rule:** every part **soldered to the board** must resolve to a row in `components-inventory/dtu_component_shop(1).csv`. Modules (ESP32 DevKit, MAX31855, SSD1306) mount on female headers / Molex and are *not* board-soldered parts.
- **Pin map:** exactly as spec §8.1. `HEATER_PWM=GPIO25, TC_SCK=GPIO18, TC_SO=GPIO19, TC_CS=GPIO5, OLED_SDA=GPIO21, OLED_SCL=GPIO22, ENC_A=GPIO32, ENC_B=GPIO33, ENC_SW=GPIO27, BTN_START=GPIO26, LED_STATUS=GPIO4`.
- **Commits:** never mention Claude/AI in commit messages (user standing rule).

## File Structure

```
hardware/kicad/
  reflow.kicad_pro            # KiCad 10 project (design rules baked in)
  reflow.kicad_sch            # schematic (generated by build script)
  reflow.kicad_pcb            # board
  fp-lib-table                # project-local, ${KIPRJMOD} relative
  sym-lib-table               # project-local
  lib/
    energy_system.pretty/     # vendored TO-220 GDS + regulator laser pads
    energy_system.kicad_sym   # vendored symbols (MOSFET/reg as needed)
    TerminalBlock.pretty/     # vendored bornier screw terminals
  modules.kicad_sym           # ESP32 DevKit V1 + MAX31855 + OLED + encoder module symbols
  modules.pretty/             # their header footprints (2x15, 1x5, 1x4, ...)
  tools/
    build_schematic.py        # component placement + net generation (project pattern)
    net_contract.py           # asserts schematic nets == net_contract.json
    verify_footprints.py      # schematic footprint refs resolve against libs
  net_contract.json           # design-of-record: nets + ESP32 pin map
  production/                 # SRM-20 mill outputs (gitignored binaries)
docs/
  BOM.md                      # generated + shop-cross-checked
  electrical-calcs.md         # pour width, regulator dissipation, gate drive
```

---

### Task 1: KiCad 10 project skeleton + vendored libraries

**Files:**
- Create: `hardware/kicad/reflow.kicad_pro`, `reflow.kicad_sch` (empty A3 sheet), `fp-lib-table`, `sym-lib-table`
- Create: `hardware/kicad/lib/` (copy `energy_system.pretty`, `energy_system.kicad_sym`, `TerminalBlock.pretty` from the DTU Electrical Energy Systems repo `hardware/kicad/lib/`)
- Create: `hardware/kicad/tools/verify_footprints.py`

**Interfaces:**
- Produces: a KiCad 10 project that opens clean; libs registered at `${KIPRJMOD}/lib/energy_system.pretty`, `${KIPRJMOD}/lib/TerminalBlock.pretty`.

- [ ] **Step 1: Write the verification first** — `tools/verify_footprints.py` (pure stdlib, no pcbnew): parse `reflow.kicad_sch`, collect every `(property "Footprint" "<lib>:<fp>")`, and assert each `<lib>:<fp>.kicad_mod` exists under a registered `.pretty`. Print `N footprints checked, M unresolved` and exit non-zero if any unresolved. Model it on the reference repo's `verify_footprints.py`.

- [ ] **Step 2: Run it — expect failure** (no project yet)

```bash
py -3.13 hardware/kicad/tools/verify_footprints.py
```
Expected: FAIL — `reflow.kicad_sch` not found / 0 footprints.

- [ ] **Step 3: Create the project + vendor libs.** Open KiCad 10, New Project `hardware/kicad/reflow`; or generate minimal `.kicad_pro`/`.kicad_sch` stubs. Copy the three libs into `hardware/kicad/lib/`. Write `fp-lib-table`:

```
(fp_lib_table
  (version 7)
  (lib (name "energy_system")(type "KiCad")(uri "${KIPRJMOD}/lib/energy_system.pretty")(options "")(descr ""))
  (lib (name "TerminalBlock")(type "KiCad")(uri "${KIPRJMOD}/lib/TerminalBlock.pretty")(options "")(descr "")))
```
and `sym-lib-table` registering `${KIPRJMOD}/lib/energy_system.kicad_sym` plus `${KIPRJMOD}/modules.kicad_sym` (created in Task 2).

- [ ] **Step 4: Bake design rules.** In `reflow.kicad_pro` set the default netclass track width `1.0` mm and clearance `0.8` mm (these are re-asserted by `pcb_build.py` later, but set them now so ERC/DRC use them).

- [ ] **Step 5: Confirm KiCad 10 CLI is the active toolchain**

```bash
"/c/Program Files/KiCad/10.0/bin/kicad-cli.exe" version
```
Expected: prints a `10.0.x` version string.

- [ ] **Step 6: Run verify — expect pass-with-zero** (empty schematic resolves trivially)

```bash
py -3.13 hardware/kicad/tools/verify_footprints.py
```
Expected: `0 footprints checked, 0 unresolved` exit 0.

- [ ] **Step 7: Commit**

```bash
git add hardware/kicad
git commit -m "hardware: KiCad 10 project skeleton + vendored footprint/symbol libs"
```

---

### Task 2: Net contract + ESP32 pin map (design of record)

**Files:**
- Create: `hardware/kicad/net_contract.json`
- Create: `hardware/kicad/tools/net_contract.py`
- Create: `hardware/kicad/modules.kicad_sym` + `hardware/kicad/modules.pretty/` (ESP32 DevKit V1, MAX31855 header, OLED header, encoder, start button)

**Interfaces:**
- Produces: `net_contract.json` — the authoritative net list and pin map every later task wires toward, and that the firmware plan consumes. Shape:
```json
{
  "module": "ESP32-DevKitV1-30pin",
  "pinmap": {"HEATER_PWM":"GPIO25","TC_SCK":"GPIO18","TC_SO":"GPIO19","TC_CS":"GPIO5",
             "OLED_SDA":"GPIO21","OLED_SCL":"GPIO22","ENC_A":"GPIO32","ENC_B":"GPIO33",
             "ENC_SW":"GPIO27","BTN_START":"GPIO26","LED_STATUS":"GPIO4"},
  "power_nets": ["+24V","+12V","+5V","+3V3","GND","HEATER_RET"],
  "nets": { "+5V": ["U2.OUT","A1.VIN","..."], "...": [] }
}
```

- [ ] **Step 1: Write the checker first** — `net_contract.py`: load `net_contract.json`, then parse `reflow.kicad_sch` and assert (a) every `pinmap` value appears as a label on the matching ESP32 pin, (b) every `power_nets` entry exists, (c) no net in `nets` has fewer than 2 endpoints. Exit non-zero on any mismatch.

- [ ] **Step 2: Run it — expect failure**

```bash
py -3.13 hardware/kicad/tools/net_contract.py
```
Expected: FAIL — `net_contract.json` missing.

- [ ] **Step 3: Author `net_contract.json`** with the exact pin map from Global Constraints, the six power nets, and the full net list (every connection the schematic must contain — power tree, gate drive, SPI, I²C, encoder, button, LED). This is the single source the wiring tasks implement.

- [ ] **Step 4: Build the module symbols/footprints.** In `modules.kicad_sym` create:
  - `ESP32_DevKitV1` — 30 pins matching the DOIT V1 silk order; footprint = two 1×15 female headers, 2.54 mm pitch, **22.86 mm** row spacing (`modules.pretty/ESP32_DevKitV1_2x15_P2.54_W22.86.kicad_mod`).
  - `MAX31855_Module` — 5-pin (VCC, GND, SCK, CS, SO) → `modules.pretty/Header_1x05_P2.54.kicad_mod`.
  - `OLED_SSD1306_I2C` — 4-pin (VCC, GND, SCL, SDA) → `Header_1x04_P2.54`.
  - Encoder + start button use shop symbols (`Encoder:Rotary`, `Switch:SW_Push`) with through-hole footprints.

- [ ] **Step 5: Validate the JSON parses and pin map equals spec**

```bash
py -3.13 -c "import json;d=json.load(open('hardware/kicad/net_contract.json'));assert d['pinmap']['HEATER_PWM']=='GPIO25';print('contract ok',len(d['nets']),'nets')"
```
Expected: `contract ok <N> nets`.

- [ ] **Step 6: Commit**

```bash
git add hardware/kicad/net_contract.json hardware/kicad/tools/net_contract.py hardware/kicad/modules.kicad_sym hardware/kicad/modules.pretty
git commit -m "hardware: net contract, pin map, and module symbols/footprints"
```

---

### Task 3: Schematic component placement

**Files:**
- Create: `hardware/kicad/tools/build_schematic.py`
- Modify: `hardware/kicad/reflow.kicad_sch`

**Interfaces:**
- Consumes: `modules.kicad_sym`, `energy_system.kicad_sym`, stock `Device:*`.
- Produces: a schematic with every component placed (no wiring yet). Reference designators below are fixed and used by all later tasks.

Component list (ref, symbol, value, footprint) — placed on an A3 sheet, power section top-left, power corner bottom-right, controller centre, UI right:

```
A1  modules:ESP32_DevKitV1   ESP32-DevKitV1   modules:ESP32_DevKitV1_2x15_P2.54_W22.86
J1  TerminalBlock:...-2_P5.08 24V_IN          TerminalBlock:TerminalBlock_bornier-2_P5.08mm
J2  TerminalBlock:...-2_P5.08 HEATER          TerminalBlock:TerminalBlock_bornier-2_P5.08mm
J3  modules:Header_1x05       MAX31855         modules:Header_1x05_P2.54
J4  modules:Header_1x04       OLED             modules:Header_1x04_P2.54
F1  Device:Fuse               15A              (inline holder — symbol only, see note)
D1  Device:D_TVS              SMBJ26A-equiv    Diode_THT:D_DO-201AD_P15.24mm_Horizontal
U2  energy_system:LM2576      LM2576-5.0       energy_system:TO-220-3_Vertical_LaserPads (+ 2 extra pins → TO-220-5 variant)
L1  Device:L                  100uH            Inductor_THT:L_Toroid_Vertical_L20.0mm
D2  Device:D_Schottky         1N5817           Diode_THT:D_DO-41_SOD81_P10.16mm_Horizontal
U3  energy_system:LM7812      LM7812           energy_system:TO-220-3_Vertical_LaserPads
Q1  Device:Q_NMOS_GDS         IRFS4710         energy_system:TO-220-3_Vertical_LaserPads_GDS
Q2  Device:Q_NMOS_GDS         BS170            Package_TO_SOT_THT:TO-92_Inline
Q3  Device:Q_NMOS_GDS         BS170            Package_TO_SOT_THT:TO-92_Inline
SW1 Switch:SW_Push            START            Button_Switch_THT:SW_PUSH_6mm
RV1 Encoder:Rotary_Encoder_Switch ENC          Rotary_Encoder:RotaryEncoder_Alps_EC11
D3  Device:LED                STATUS           LED_THT:LED_D5.0mm
R1..R12, C1..C8  Device:R / Device:C  (values assigned in wiring tasks)  THT axial / disc
```
Note `LM2576` is a 5-pin TO-220; if the lib has only a 3-pin laser pad, add a `TO-220-5_Vertical_LaserPads` variant in Task 1's lib copy or generate it with `lib/make_laserpads.py` from the reference repo.

- [ ] **Step 1: Write the placement-check test** — extend `verify_footprints.py` invocation expectation: a one-liner that greps the saved schematic for each required refdes.

```bash
py -3.13 -c "s=open('hardware/kicad/reflow.kicad_sch').read();req=['A1','J1','J2','J3','J4','U2','U3','Q1','Q2','Q3','SW1','RV1','D3'];missing=[r for r in req if f'\"{r}\"' not in s];print('MISSING',missing);assert not missing"
```

- [ ] **Step 2: Run it — expect failure** (schematic still empty). Expected: `MISSING [...]`, assertion error.

- [ ] **Step 3: Write `build_schematic.py`** following `build_v1_schematic.py`: a `COMPONENTS` list of `(ref, lib_id, value, footprint, x, y, angle)` for every part above, writing valid KiCad-10 `(symbol ...)` blocks with fresh UUIDs into `reflow.kicad_sch`. Back up the prior schematic first (project convention).

- [ ] **Step 4: Run the build, then the placement check**

```bash
py -3.13 hardware/kicad/tools/build_schematic.py
py -3.13 -c "s=open('hardware/kicad/reflow.kicad_sch').read();req=['A1','J1','J2','J3','J4','U2','U3','Q1','Q2','Q3','SW1','RV1','D3'];missing=[r for r in req if f'\"{r}\"' not in s];print('MISSING',missing);assert not missing"
```
Expected: `MISSING []`.

- [ ] **Step 5: Confirm the schematic opens via CLI (no parse error)**

```bash
"/c/Program Files/KiCad/10.0/bin/kicad-cli.exe" sch export svg -o hardware/kicad/_smoke.svg hardware/kicad/reflow.kicad_sch
```
Expected: an SVG is produced (placement only; unconnected). Delete `_smoke.svg` after.

- [ ] **Step 6: Commit**

```bash
git add hardware/kicad/tools/build_schematic.py hardware/kicad/reflow.kicad_sch
git commit -m "hardware: place all schematic components"
```

---

### Task 4: Wire the power input + protection + regulators

**Files:**
- Modify: `hardware/kicad/tools/build_schematic.py` (add a `NETS_POWER` wiring pass), `reflow.kicad_sch`
- Create: `docs/electrical-calcs.md` (regulator dissipation section)

**Interfaces:**
- Consumes: placed components from Task 3.
- Produces: connected nets `+24V, +12V, +5V, GND` per `net_contract.json`.

Connections to realise (labels/wires):
- `J1.1 → +24V` through `F1` (fuse) then to the `+24V` rail; `J1.2 → GND`. `D1` (TVS) from `+24V` to `GND` at the input.
- LM2576 buck: `U2.Vin=+24V`, `U2.GND=GND`, `U2.FB`/`ON` per the 5.0-fixed topology, `U2.OUT → L1 → +5V`, `D2` (1N5817) cathode to the OUT/L1 node, anode to GND (catch diode), `C_in` 100 µF across +24V/GND, `C_out` 1000 µF across +5V/GND. Values from the LM2576-5.0 datasheet fixed-output app circuit.
- `U3` LM7812: `IN=+24V`, `GND=GND`, `OUT=+12V`, with 0.33 µF in / 0.1 µF out.

- [ ] **Step 1: Add the ERC gate.** Define the check command used from here on:

```bash
"/c/Program Files/KiCad/10.0/bin/kicad-cli.exe" sch erc --severity-error --exit-code-violations -o hardware/kicad/_erc.rpt hardware/kicad/reflow.kicad_sch
```
This task's acceptance: the `+24V/+12V/+5V/GND` nets show **no "unconnected"/"no-driver"** ERC errors (other sections may still error until their tasks).

- [ ] **Step 2: Run ERC now — expect power-net errors** (regulators floating). Expected: nonzero exit, unconnected-pin errors on U2/U3/L1/D2.

- [ ] **Step 3: Implement `NETS_POWER`** in `build_schematic.py`: add wires/labels/`PWR_FLAG`s realising the connections above. Add the LM2576 support passives (`C1`=100µF/35V in, `C2`=1000µF/16V out, `L1`=100µH, `D2`=1N5817) with values.

- [ ] **Step 4: Write the calc** in `docs/electrical-calcs.md`: LM2576 at 5 V/Iload (ESP32+OLED ≈ 0.5 A) — switcher, low loss; LM7812 dissipation = (24−12)×I_gatedrive_avg, show I_avg ≈ a few mA so P < 0.1 W (no heatsink). Confirm input cap ripple-current rating.

- [ ] **Step 5: Re-run ERC — expect power nets clean**

```bash
"/c/Program Files/KiCad/10.0/bin/kicad-cli.exe" sch erc --exit-code-violations -o hardware/kicad/_erc.rpt hardware/kicad/reflow.kicad_sch; grep -iE "U2|U3|L1|D2|\+5V|\+12V|\+24V" hardware/kicad/_erc.rpt || echo "no power-net violations"
```
Expected: `no power-net violations` (or only acknowledged ones).

- [ ] **Step 6: Commit**

```bash
git add hardware/kicad/tools/build_schematic.py hardware/kicad/reflow.kicad_sch docs/electrical-calcs.md
git commit -m "hardware: wire 24V input protection, LM2576 5V, LM7812 12V rails"
```

---

### Task 5: Wire the power stage (MOSFET + boot-safe gate drive)

**Files:**
- Modify: `build_schematic.py` (`NETS_POWERSTAGE` pass), `reflow.kicad_sch`, `docs/electrical-calcs.md`

**Interfaces:**
- Consumes: `+12V`, `GND`, `HEATER_PWM` label, `J2` heater terminal.
- Produces: nets `HEATER_RET` (Q1 drain), `GATE_MAIN` (Q1 gate), `GD_NODE1` (inter-stage).

Two-stage **non-inverting, boot-safe** level shifter (GPIO high → heater on; low/floating → off):
- Stage 1 inverter: `R1` (100 kΩ) gate pulldown on `Q2.G` to GND; `HEATER_PWM → R2 (1 kΩ) → Q2.G`; `Q2.S=GND`; `Q2.D = GD_NODE1`; `R3` (10 kΩ) pull-up `GD_NODE1 → +12V`.
- Stage 2 inverter: `GD_NODE1 → Q3.G`; `Q3.S=GND`; `Q3.D = GATE_MAIN`; `R4` (10 kΩ) pull-up `GATE_MAIN → +12V`; `R5` (100 Ω) is the series gate resistor from `GATE_MAIN` to `Q1.G`; `R6` (10 kΩ) gate-source pulldown `Q1.G → GND`.
- Power loop: `J2.1 = +24V` (heater +), `J2.2 = HEATER_RET`; `Q1.D = HEATER_RET`, `Q1.S = GND`. `D4` TVS (e.g. SMBJ33-equiv THT) across `HEATER_RET → GND` clamps drain transients.

Boot-state proof to record: GPIO floating → `Q2` off → `GD_NODE1` = +12 V → `Q3` on → `GATE_MAIN` = 0 V → `Q1` off. ✓

- [ ] **Step 1: Add the boot-safety assertion test** — `tools/check_gate_boot_safe.py`: parse the netlist; assert `GATE_MAIN` has a path to GND through `Q3` and a pull *down* dominates when `HEATER_PWM` is low (encode as: `R6` connects `Q1.G`→GND, and `GD_NODE1` pull-up to +12V exists). Exit nonzero if the inverting (single-stage) pattern is detected (`HEATER_PWM` pull-up directly to gate).

- [ ] **Step 2: Run it — expect failure** (stage not wired). Expected: nonzero exit.

- [ ] **Step 3: Implement `NETS_POWERSTAGE`** with the connections + resistor values above; add `Q3`, `D4`, `R1..R6` values.

- [ ] **Step 4: Add the power calcs** to `docs/electrical-calcs.md`: Q1 conduction loss = I²·Rds(on) = 13²×0.014 ≈ 2.4 W → TO-220 heatsink + pad; gate charge vs. 12 V/Rg switching time ≪ PWM period; confirm Vgs=12 V < Vgs(max) 20 V and ≫ Vgs(th).

- [ ] **Step 5: Run the boot-safety check + ERC**

```bash
py -3.13 hardware/kicad/tools/check_gate_boot_safe.py && "/c/Program Files/KiCad/10.0/bin/kicad-cli.exe" sch erc --exit-code-violations -o hardware/kicad/_erc.rpt hardware/kicad/reflow.kicad_sch; grep -iE "Q1|Q2|Q3|GATE_MAIN|HEATER_RET" hardware/kicad/_erc.rpt || echo "power stage clean"
```
Expected: boot-safe check exit 0; `power stage clean`.

- [ ] **Step 6: Commit**

```bash
git add hardware/kicad/tools/build_schematic.py hardware/kicad/tools/check_gate_boot_safe.py hardware/kicad/reflow.kicad_sch docs/electrical-calcs.md
git commit -m "hardware: wire IRFS4710 power stage with boot-safe two-stage gate drive"
```

---

### Task 6: Wire the controller (ESP32 + MAX31855 + OLED + encoder + button + LED)

**Files:**
- Modify: `build_schematic.py` (`NETS_CTRL` pass), `reflow.kicad_sch`

**Interfaces:**
- Consumes: `+5V`, `+3V3` (from A1's regulator pin), `GND`, `HEATER_PWM`.
- Produces: every `pinmap` net from `net_contract.json` realised on the ESP32 pins.

Connections (per spec §8.1):
- `A1.VIN=+5V`, `A1.GND=GND`, `A1.3V3 = +3V3`.
- MAX31855 `J3`: `VCC=+3V3, GND=GND, SCK=A1.GPIO18, CS=A1.GPIO5, SO=A1.GPIO19`.
- OLED `J4`: `VCC=+3V3, GND=GND, SCL=A1.GPIO22, SDA=A1.GPIO21`.
- Encoder `RV1`: `A=A1.GPIO32, B=A1.GPIO33, SW=A1.GPIO27`, common=GND (firmware uses internal pull-ups; add 10 nF `C7/C8` A→GND, B→GND debounce).
- Start button `SW1`: `A1.GPIO26 → SW1 → GND`.
- Status LED `D3`: `A1.GPIO4 → R7 (330 Ω) → D3 → GND`.
- `HEATER_PWM` net = `A1.GPIO25` (already consumed by Task 5).
- Decoupling: `C5` 100 nF at `J3.VCC`, `C6` 100 nF at `J4.VCC`.

- [ ] **Step 1:** Re-use `net_contract.py` as the gate (it asserts every pinmap label lands on the right ESP32 pin). Run it — **expect failure** (controller unwired).

- [ ] **Step 2:** Confirm the failure lists the missing pin labels. Expected: nonzero exit naming `GPIO18/19/5/21/22/32/33/27/26/4`.

- [ ] **Step 3: Implement `NETS_CTRL`** with all connections above.

- [ ] **Step 4: Run the contract check**

```bash
py -3.13 hardware/kicad/tools/net_contract.py
```
Expected: exit 0, `contract satisfied`.

- [ ] **Step 5: Commit**

```bash
git add hardware/kicad/tools/build_schematic.py hardware/kicad/reflow.kicad_sch
git commit -m "hardware: wire ESP32, MAX31855 SPI, OLED I2C, encoder, button, status LED"
```

---

### Task 7: Footprints assigned + full ERC clean

**Files:**
- Modify: `reflow.kicad_sch` (footprint properties), `docs/electrical-calcs.md`

- [ ] **Step 1:** Ensure every symbol has its footprint set (per Task 3 table). Reference `kicad-laser-pcb` `references/footprints.md` for the through-hole footprint conventions and the `_GDS` TO-220 trap (MOSFET pins are G/D/S, must use the `_GDS` pad-named footprint or pads get no net silently).

- [ ] **Step 2: Run full ERC — expect zero errors**

```bash
"/c/Program Files/KiCad/10.0/bin/kicad-cli.exe" sch erc --exit-code-violations --severity-error -o hardware/kicad/erc.rpt hardware/kicad/reflow.kicad_sch
```
Expected: exit 0. If any remain, fix wiring/PWR_FLAG and re-run.

- [ ] **Step 3: Run footprint verify**

```bash
py -3.13 hardware/kicad/tools/verify_footprints.py
```
Expected: `<N> footprints checked, 0 unresolved`.

- [ ] **Step 4: Finalise `docs/electrical-calcs.md`** with the **pour-width** requirement for Task 9: 13 A on 35 µm copper at ≤20 °C rise → required width via IPC-2221 (≈ 8–10 mm); record the target so layout can be checked against it.

- [ ] **Step 5: Commit**

```bash
git add hardware/kicad/reflow.kicad_sch hardware/kicad/erc.rpt docs/electrical-calcs.md
git commit -m "hardware: assign footprints, ERC clean, finalize electrical calcs"
```

---

### Task 8: BOM generation + DTU shop cross-check

**Files:**
- Create: `docs/BOM.md`
- Create: `hardware/kicad/tools/check_bom_against_shop.py`

- [ ] **Step 1: Write the cross-check first** — `check_bom_against_shop.py`: read the schematic's board-soldered parts (exclude `A1/J3/J4` modules + the encoder/button which are hand-mounted), normalise each value, and assert it matches a `Part_Number`/`Value` row in `components-inventory/dtu_component_shop(1).csv`. Print any part with no shop match.

- [ ] **Step 2: Run it — expect failure** (no BOM yet / unmatched parts). Expected: nonzero exit listing unmatched values.

- [ ] **Step 3: Generate the BOM** with the skill script and resolve mismatches by snapping values to the nearest shop stock (E96 resistors, electrolytic/ceramic caps, IRFS4710, BS170, LM2576, LM7812, 1N5817, TVS, bornier terminals):

```bash
py -3.13 "C:/Users/Mads2/.claude/skills/kicad-laser-pcb/scripts/bom_to_md.py" hardware/kicad/reflow.kicad_sch -o docs/BOM.md
```

- [ ] **Step 4: Re-run the cross-check — expect pass**

```bash
py -3.13 hardware/kicad/tools/check_bom_against_shop.py
```
Expected: `all board parts resolve to DTU shop`. Externals (ESP32, MAX31855, OLED, PSU, plate, fuses) listed in a separate "bring-your-own" section of `docs/BOM.md`.

- [ ] **Step 5: Commit**

```bash
git add docs/BOM.md hardware/kicad/tools/check_bom_against_shop.py
git commit -m "hardware: BOM generated and cross-checked against DTU component shop"
```

---

### Task 9: Board build + zone layout + DRC

**Files:**
- Create: `hardware/kicad/reflow.kicad_pcb`

- [ ] **Step 1: Build the board from the schematic** with the skill, KiCad-10 libs on the path:

```powershell
$env:KICAD_LASER_EXTRA_LIBS="C:\Users\Mads2\Documents\Projects\esp32-reflow-hotplate\hardware\kicad\lib"
py -3.13 "C:\Users\Mads2\.claude\skills\kicad-laser-pcb\scripts\pcb_build.py" "hardware\kicad\reflow.kicad_pcb" --from-sch "hardware\kicad\reflow.kicad_sch"
```
Expected: a `.kicad_pcb` with all footprints loaded, netclass at 1.0/0.8 mm.

- [ ] **Step 2: Place components into zones.** Power corner (J1, F1, D1, U2, L1, D2, U3, Q1+heatsink, J2) in one corner; controller (A1, J3, J4) centre; UI (RV1, SW1, D3) along one edge; keep the analog MAX31855 header away from Q1. The ESP32 module footprint must have clear board under it (no traces crossing where the metal can short — it sits on headers, so fine).

- [ ] **Step 3: Add wide copper pours** for `+24V` and `HEATER_RET` between J1/J2 and Q1 — ≥ the width recorded in `docs/electrical-calcs.md` (≈8–10 mm). Keep the 13 A loop short.

- [ ] **Step 4: Run DRC — expect clean**

```bash
"/c/Program Files/KiCad/10.0/bin/kicad-cli.exe" pcb drc --exit-code-violations --severity-error -o hardware/kicad/drc.rpt hardware/kicad/reflow.kicad_pcb
```
Expected: exit 0 (unrouted ratsnest is allowed pre-route; copper-rule violations are not).

- [ ] **Step 5: Commit**

```bash
git add hardware/kicad/reflow.kicad_pcb hardware/kicad/drc.rpt
git commit -m "hardware: build board, zone the power corner, add high-current pours"
```

---

### Task 10: Route (single-sided) + top jumpers + DRC

**Files:**
- Modify: `hardware/kicad/reflow.kicad_pcb`
- Create: `hardware/kicad/production/reflow_top_cu.dxf`

- [ ] **Step 1: Two-stage Freerouting** via the skill (KiCad-10 binary override):

```powershell
& "C:\Users\Mads2\.claude\skills\kicad-laser-pcb\scripts\route_board.ps1" -Board "hardware\kicad\reflow.kicad_pcb" -KicadBin "C:\Program Files\KiCad\10.0\bin"
```
Expected: B.Cu routed; nets that can't route single-sided left as top-side jumpers.

- [ ] **Step 2: Resolve remaining nets as wire bridges** on F.Cu and export the jumper drawing `reflow_top_cu.dxf` (the wiring guide), per the laser/mill single-sided flow.

- [ ] **Step 3: Run DRC — expect clean, fully routed**

```bash
"/c/Program Files/KiCad/10.0/bin/kicad-cli.exe" pcb drc --exit-code-violations --severity-error -o hardware/kicad/drc.rpt hardware/kicad/reflow.kicad_pcb
```
Expected: exit 0, no unconnected items.

- [ ] **Step 4: Commit**

```bash
git add hardware/kicad/reflow.kicad_pcb hardware/kicad/production/reflow_top_cu.dxf
git commit -m "hardware: route single-sided board with top-side jumpers"
```

---

### Task 11: Production export for SRM-20 mill

**Files:**
- Create: `hardware/kicad/production/reflow_mill_bcu.svg`, `reflow-Edge_Cuts.*`, drill files, and the milling note `production/MILL_NOTES.md`

- [ ] **Step 1: Export production set** (Gerbers/DXF) with the skill:

```powershell
& "C:\Users\Mads2\.claude\skills\kicad-laser-pcb\scripts\export_production.ps1" -Board "hardware\kicad\reflow.kicad_pcb" -KicadBin "C:\Program Files\KiCad\10.0\bin"
```

- [ ] **Step 2: Make the mirrored B.Cu SVG** for mods/`gerber2rml` (per `SRM20_MILL.md`):

```powershell
& "C:\Program Files\KiCad\10.0\bin\kicad-cli.exe" pcb export svg -o hardware\kicad\production\reflow_mill_bcu.svg -l "B.Cu" --mirror --black-and-white --page-size-mode 2 --exclude-drawing-sheet hardware\kicad\reflow.kicad_pcb
```

- [ ] **Step 3: Write `production/MILL_NOTES.md`** capturing the three SRM-20 jobs from `SRM20_MILL.md`: traces (1/64", 2 offsets, mirrored), holes + cutout (1/32"), FR-1 stock, origin/Z-zero procedure, and the multimeter continuity check after. Note the **wide pours need full clearing** around them (mods `-1` offsets there or verify the 1/64" clears the 0.8 mm channels).

- [ ] **Step 4: Verify the export set exists**

```bash
ls -1 hardware/kicad/production/
```
Expected: the mirrored B.Cu SVG, Edge.Cuts, drill, and `reflow_top_cu.dxf` all present.

- [ ] **Step 5: Commit**

```bash
git add hardware/kicad/production docs
git commit -m "hardware: export SRM-20 mill production files and milling notes"
```

---

## Self-Review notes (for the executor)

- **Heater plate is the open input (spec §9):** the schematic only needs 24 V / ~13 A, which is fixed — so this plan is *not* blocked. The exact fuse value (Task 3 `F1`) and final pour width (Task 9) should be re-confirmed once the real plate's wattage is known; both are called out where they're used.
- **LM2576 5-pin footprint:** if the vendored `energy_system.pretty` lacks a 5-pin TO-220 laser pad, generate one with the reference repo's `lib/make_laserpads.py` during Task 1 — don't substitute a 3-pin pad.
- **ERC/DRC are the real gates:** every wiring task ends on a clean ERC for its section; Tasks 9–10 end on clean DRC. Do not advance a task with violations in its own section.

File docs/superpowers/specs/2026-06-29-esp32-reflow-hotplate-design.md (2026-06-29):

# ESP32 SMD Reflow Hotplate — Design Spec

**Date:** 2026-06-29
**Status:** Approved (brainstorming complete; ready for implementation planning)

## 1. Goal

Build, entirely from scratch, an ESP32-controlled SMD reflow hotplate that reflows
small/medium SMD boards (up to ~100 × 100 mm) by tracking a PID-controlled reflow
temperature profile. Deliverables: a KiCad schematic, a CNC-milled single-sided control
board, ESP32 firmware, and 3D-printed enclosure parts.

### Non-goals (YAGNI)
- No mains-voltage (AC) heating. The whole build is 24 V DC.
- No WiFi/web UI in the first version (the ESP32 supports it; left as a later add-on).
- No reflow-camera, no automatic profile learning, no multi-zone heating.

## 2. Key decisions (from brainstorming)

| Decision | Choice | Reason |
|---|---|---|
| Heater | 24 V DC PTC aluminium plate, ~300 W (~13 A) | Mains-free; real reflow temps; ~100×100 mm board area |
| Power switch | IRFS4710 N-MOSFET (low-side), 12 V gate drive | Lowest Rds(on) in DTU shop (~14 mΩ); logic-level parts too hot at 13 A |
| Temp sensing | K-type thermocouple + MAX31855 (SPI) | Reflow standard; cold-junction compensated; open-TC fault detect |
| Logic supply | 24 V → 5 V via LM2576 switcher | Linear 7805 would dissipate ~9 W across the 19 V drop |
| Gate supply | 24 V → 12 V via LM7812 linear | Gate draws ~0 average (slow PWM), linear is fine |
| UI | SSD1306 OLED (I²C) + rotary encoder + start/stop button | Standalone, no phone/network needed |
| Control board | Single-sided through-hole, CNC-milled (Roland SRM-20) | Matches DTU mill/laser process and shop stock |
| Enclosure | 3D-printed, offset electronics box + metal-standoff plate mount | Plastic must never touch the ~250 °C plate |
| Architecture | Approach A: single control board, high-current path as wide copper pours | One milling job, one enclosure, isolated "power corner" |

## 3. Architecture

### 3.1 Power tree
```
24 V PSU ──┬─► LM2576 switching reg ──► 5 V ──► ESP32 DevKit VIN
           │                                    └► ESP32 3.3 V LDO ─► MAX31855, OLED, encoder
           ├─► LM7812 linear reg ─────► 12 V ──► MOSFET gate-drive rail
           └─► (fused, ~15 A) ─────────► heater(+) / IRFS4710 / return  [13 A power loop]
```

### 3.2 Power stage ("power corner")
- **IRFS4710** low-side N-MOSFET switches the heater negative return. ~2.4 W at 13 A →
  TO-220 heatsink + mica/silicon insulating pad (DTU shop).
- Gate drive: ESP32 3.3 V PWM → **two-stage BS170 level shifter (non-inverting overall)**
  → IRFS4710 gate at **12 V** through a gate resistor, plus a **gate-source pulldown**.
  The topology is **boot-safe**: GPIO high = heater ON; GPIO low / floating / ESP32
  unpowered / mid-reset = heater **OFF inherently** (no firmware required for the safe
  state). A single inverting shifter is explicitly rejected because it would drive the
  heater ON whenever the GPIO floats at boot/crash.
- Heater is resistive → no freewheel diode. **TVS** across 24 V input clamps transients.
- PWM is "slow" (≤ a few hundred Hz; thermal mass tolerates even ~2 Hz), so switching
  losses are negligible and gate-drive current is tiny.
- **High-current routing:** heater current flows only through short, wide copper **pours**
  (≈8–10 mm) between the screw terminals and the MOSFET — never through 1 mm signal
  traces. The mill isolates around the pour at no extra cost.

### 3.3 Temperature sensing
- K-type thermocouple bonded to the plate underside → **MAX31855** breakout on the ESP32
  hardware SPI bus (CS, SCK, SO — read-only; only SPI device). Provides ±2 °C accuracy,
  cold-junction compensation, and open/short fault flags consumed by the safety module.

### 3.4 Safety (layered)
1. **Hardware fail-safe:** non-inverting gate drive + gate-source pulldown → power-off /
   reset / crash / floating GPIO = heater off, with no firmware involvement.
2. **Inline thermal cutoff fuse** (~240 °C one-shot) in series with the heater element —
   independent of firmware.
3. **Fused 24 V input** (~15 A inline) + input TVS.
4. **Firmware watchdog:** thermal-runaway detection (heater commanded on but temperature
   not rising), hard over-temperature limit, MAX31855 open/short-TC fault → immediate
   shutdown; start/stop button forces idle at any time.

## 4. Components & sourcing

**From DTU component shop (through-hole lab stock):**
IRFS4710 (power MOSFET), 2× BS170 (non-inverting gate level shifter), LM2576 (5 V switcher), LM7812 (12 V),
TVS diode, all resistors/capacitors, 2- & 3-pole screw terminals (`TerminalBlock.pretty`),
rotary encoder, momentary pushbutton, TO-220 heatsink + thermal pad, headers/Molex,
IC sockets as needed.

**External modules / hardware (not lab stock — bring your own):**
ESP32 DevKit module, MAX31855 + K-type thermocouple module, SSD1306 OLED, 24 V DC PSU
(~15 A / 360 W), 24 V DC PTC aluminium heater plate (~100×100 mm, ~300 W), inline thermal
cutoff fuse, inline 24 V fuse holder + fuse.

A complete BOM with shop part numbers and quantities is produced during implementation
(`docs/BOM.md`).

## 5. Control board (KiCad 10)

- **Conventions reused from the DTU Electrical Energy Systems project:**
  - Footprints: `energy_system.pretty` — TO-220 **G/D/S** laser-pad variant for the MOSFET
    (avoids the numeric-vs-letter pad-name trap), plain TO-220 laser pad for regulators;
    `TerminalBlock.pretty` bornier P5.08 mm screw terminals.
  - Symbols: `energy_system.kicad_sym` where applicable; stock `Device:*` otherwise
    (e.g. `Device:Q_NMOS` paired with the `_GDS` footprint).
  - Project-local `fp-lib-table` with `${KIPRJMOD}` relative paths (portable across PCs).
  - KiCad **10.0** CLI/toolchain (file format 20260306).
- **Design rules:** single-sided, through-hole, **1.0 mm trace / 0.8 mm clearance**; top-
  layer nets realised as wire bridges, exported as `*_top_cu.dxf`.
- **Layout zoning:** isolated **power corner** (24 V-in / heater-out terminals → IRFS4710
  + heatsink → return, fat pours) kept physically clear of the **logic/analog zone**
  (ESP32 headers, MAX31855 header, OLED/encoder/button connectors, gate-drive small-signal).
- **Module mounting:** ESP32 DevKit, OLED, encoder mount on female headers / Molex so the
  board is low-profile and modules are replaceable; only shop through-hole parts are
  soldered to the board itself.
- **Connectors:** screw terminals for 24 V-in, heater-out, thermocouple; Molex/headers for
  OLED (I²C), encoder, start/stop button.
- **Production:** routed via the kicad-laser-pcb skill's rules, then milled on the SRM-20
  (SVG → 1000 dpi PNG → mods/`gerber2rml` → `.rml`/`.nc`), single setup, FR-1 preferred.

## 6. Firmware (ESP32, PlatformIO / Arduino framework)

Modular, each unit independently testable:

| Module | Responsibility | Depends on |
|---|---|---|
| `thermocouple` | MAX31855 SPI read; temperature + fault flags | SPI |
| `heater` | PWM duty → gate drive; fail-safe off; slow-PWM | GPIO/LEDC |
| `pid` | temperature error → heater duty (anti-windup) | — |
| `profile` | reflow curve as setpoint-vs-time (preheat→soak→reflow→cool) | — |
| `safety` | runaway / over-temp / TC-open watchdog; hard cutoff | thermocouple, heater |
| `ui` | OLED render + encoder/button input | I²C, GPIO |
| `controller` | top-level state machine (idle → run stages → cooldown → done) | all |

- **Built-in profiles:** leaded **Sn63/Pb37** and lead-free **SAC305**; profiles are data,
  so adding more is editing a table.
- **Control:** PID with anti-windup; conservative default gains plus a documented tuning
  procedure for first runs.
- **State machine:** idle/select → preheat → soak → reflow → cooldown → done; start/stop
  button and any safety fault transition to a safe idle with the heater forced off.

## 7. 3D-printed enclosure (Blender → STL/STEP)

**Critical thermal rule:** the ~250 °C plate must never contact printed plastic. The plate
mounts on **metal standoffs** rising from the base, with an **air gap** above the
electronics. Base printed in **PETG** (better heat tolerance than PLA); the hot zone is all
metal.

Parts:
1. **Base tray** — standoff bosses for the metal plate mounts, feet.
2. **Electronics box** — offset from the plate's heat plume; holds the control board.
3. **Front panel** — cut-outs for OLED, encoder, start/stop button.
4. **Cable path** — routed channel between box and plate; vents over regulators / MOSFET
   heatsink.

Modeled in Blender (MCP-connected), exported to STL (print) and STEP (CAD interchange).

## 8. Repository layout
```
docs/            this spec, BOM, sourcing + tuning notes
hardware/kicad/   KiCad 10 project (schematic + single-sided board) + project fp-lib-table
hardware/3d/      Blender sources + exported STL/STEP
firmware/         PlatformIO ESP32 project (modules per §6)
```

## 8.1 ESP32 GPIO pin map (hardware ↔ firmware contract)

Default module: **30-pin DOIT ESP32 DevKit V1** (2×15 female headers, 2.54 mm pitch,
22.86 mm row spacing). All listed GPIOs are exposed on this board. If a 38-pin
ESP32-DevKitC is used instead, only the footprint widens (to 2×19) — the pin map is
unchanged.

| Signal | GPIO | Notes |
|---|---|---|
| `HEATER_PWM` | GPIO25 | LEDC PWM → two-stage BS170 gate drive; low at reset = OFF |
| `TC_SCK` | GPIO18 | VSPI clock (MAX31855) |
| `TC_SO` (MISO) | GPIO19 | VSPI MISO (MAX31855 data out; read-only, no MOSI) |
| `TC_CS` | GPIO5 | MAX31855 chip select |
| `OLED_SDA` | GPIO21 | I²C data (SSD1306) |
| `OLED_SCL` | GPIO22 | I²C clock (SSD1306) |
| `ENC_A` | GPIO32 | Rotary encoder A, internal pull-up |
| `ENC_B` | GPIO33 | Rotary encoder B, internal pull-up |
| `ENC_SW` | GPIO27 | Encoder push, internal pull-up |
| `BTN_START` | GPIO26 | Start/stop + panic, internal pull-up |
| `LED_STATUS` | GPIO4 | Status LED (avoids strapping pins) |

Strapping pins (GPIO0/2/12/15) and flash pins (GPIO6–11) are deliberately unused.

## 9. Risks & open items
- **Heater plate spec:** exact PTC plate dimensions/wattage/voltage must be fixed before
  the plate-mount frame and fuse rating are finalised.
- **13 A on FR-1:** wide pours assumed adequate for 35 µm copper; verify pour width / temp
  rise during layout (target ≤ ~20 °C rise) and keep the power loop short.
- **Gate drive at 12 V:** confirm IRFS4710 is fully enhanced and within Vgs(max) ±20 V.
- **PID tuning:** first-run autotune/manual tuning expected; ship safe conservative gains.
- **PETG vs. heat:** confirm enclosure standoff geometry keeps all plastic well below the
  glass-transition temperature under sustained reflow runs.

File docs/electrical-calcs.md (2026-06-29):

# Electrical calculations

Design-of-record: `hardware/kicad/net_contract.json`. This document captures the
quantitative justification for the power tree wired in Task 4 (24 V input
protection + the two regulators). Other sections (heater power stage, gate
drive, controller) are documented with their respective tasks.

## 1. Power tree overview

```
24 V DC ──[F1 fuse]──┬── +24V rail ──┬── U2  LM2575-ADJ buck ─── +5V  (ESP32 + OLED)
        (D3 TVS to GND)              ├── U3  LM7812 linear   ── +12V (gate-drive VCC)
                                     └── J2.1 heater terminal (switched low-side by Q1)
```

- **U2 = LM2575-ADJ** — adjustable SIMPLE SWITCHER step-down (buck), 1 A, output
  programmed to **5.03 V** by the R7/R8 feedback divider (see §3). The DTU
  component shop stocks the *adjustable* LM2575 (`IC,Linear,LM2575,Step-Down
  Adjustable Voltage Switching Regulator`), not the fixed LM2576-5.0, so the
  design uses the ADJ part plus a divider. Same 5-pin TO-220 pinout
  (1=Vin 2=Out 3=GND 4=FB 5=ON/OFF) and footprint as the fixed part.
- **U3 = LM7812** — TO-220 linear regulator, fixed 12 V output.
- There is **no separate 3V3 regulator**: +3V3 is produced by the ESP32
  DevKit's on-board LDO from +5V (handled in Task 6).

Input fusing and protection: F1 (fuse) in series with the 24 V hot lead, and
D3 (TVS) clamping +24V → GND at the input.

## 2. Load budget

| Rail | Consumers | Estimated load |
|---|---|---|
| +5V  | ESP32-DevKitV1 (Wi-Fi idle/active), SSD1306 OLED, MAX31855 | ~0.30–0.50 A (use **0.5 A** worst case) |
| +12V | Two-stage BS170 gate drive for the heater MOSFET — average current is only the gate-charge shuttling current at the PWM rate | **a few mA** average (see §4) |

## 3. LM2575-ADJ buck (24 V → 5 V)

A buck converter's loss is dominated by switching + conduction in the internal
switch and the catch diode, **not** by `(Vin − Vout)·Iload` (that term is the
linear-regulator penalty a switcher specifically avoids).

- Output power delivered: `Pout = 5 V × 0.5 A = 2.5 W`.
- LM2575 typical efficiency at this operating point (Vin = 24 V, Vout = 5 V,
  Io = 0.5 A) is roughly **75–80 %** per the datasheet efficiency curves.
- Input power: `Pin ≈ Pout / η ≈ 2.5 / 0.77 ≈ 3.25 W`, drawing
  `Iin ≈ 3.25 W / 24 V ≈ 0.14 A` from the 24 V rail.
- Regulator dissipation: `Pdiss ≈ Pin − Pout ≈ 0.75 W`, shared between the IC
  switch and the external catch diode D2.

By comparison, a **linear** 24 V → 5 V regulator at 0.5 A would burn
`(24 − 5) × 0.5 = 9.5 W` — which is exactly why the buck is used here. With
~0.75 W spread across the package and diode, the LM2575-ADJ needs only a modest
clip-on heatsink (or none, with copper pour) for this load. The LM2575 is the
**1 A** member of the family (vs the LM2576's 3 A); at the ~0.14 A input /
~0.5 A output of this design the 1 A rating is ample (≈ 2× margin on the output
load and far above the ~0.14 A drawn from the 24 V rail).

### Output-voltage feedback divider (LM2575-ADJ)

The adjustable LM2575 regulates its **FB pin (4)** to the internal reference
`Vref = 1.23 V`. A resistor divider from the +5V output node into FB sets the
output:

```
Vout = Vref · (1 + R7/R8)        Vref = 1.23 V   (LM2575-ADJ datasheet)
```

Using DTU-shop E96 values **R7 (top) = 3K09**, **R8 (bot) = 1K00**:

```
Vout = 1.23 · (1 + 3090/1000) = 1.23 · 4.09 ≈ 5.03 V
```

so the +5V rail lands at **≈ 5.03 V** (within the ESP32 DevKit VIN tolerance and
the OLED/MAX31855 supply range; the on-board AMS1117 LDO drops it to 3.3 V).
Divider current `≈ 5.03 V / (3090 + 1000) = 1.23 mA` keeps the divider stiff
against the FB pin's ~µA bias current while wasting negligible power. Topology:
`+5V → R7 → VFB(=FB pin 4) → R8 → GND`. Both `3K09` and `1K00` are stocked in
`components-inventory/dtu_component_shop(1).csv` (E96 standard).

| Ref | Value | Role | Shop part |
|-----|---|---|---|
| R7 | **3.09 kΩ** (3K09) | FB divider top, +5V → VFB | `Resistor,E96 Standard,3K09` |
| R8 | **1.00 kΩ** (1K00) | FB divider bottom, VFB → GND | `Resistor,E96 Standard,1K00` |

### Support passives (LM2575-ADJ application circuit)

Values are TI datasheet "typical application" parts, chosen from the DTU
component shop (`components-inventory/dtu_component_shop(1).csv`):

| Ref | Value | Role | Shop part |
|-----|---|---|---|
| C1 | **100 µF** electrolytic (≥ 35 V) | Input bulk cap, +24V→GND | `Capacitor,Electrolytic,100µF` (use a ≥ 35 V can for the 24 V rail) |
| L1 | **120 µH** | Buck inductor, switch node → +5V | `Inductor,Through-hole,120µ 1A` |
| D2 | **1N5817** (1 A Schottky) | Catch diode, cathode at switch node, anode to GND | `Diode,Schottky,1N5817` |
| C2 | **1000 µF** electrolytic (≥ 16 V) | Output cap, +5V→GND | `Capacitor,Electrolytic,1000µF 50V` |

These match the LM2575/LM2576 buck reference design (100 µH / 1000 µF /
1N5817 are the datasheet-recommended values for this class of load); the same
power-path passives apply to the LM2575-ADJ, which differs from the fixed part
only in the FB divider above.

#### Inductor current rating

Peak inductor current ≈ `Iout + ΔI_L/2`. With Vin = 24 V, Vout = 5 V,
f = 52 kHz, L = 120 µH the ripple is

```
ΔI_L = Vout · (1 − Vout/Vin) / (L · f)
     = 5 · (1 − 5/24) / (120e-6 · 52e3)
     = 5 · 0.792 / 6.24 ≈ 0.63 A(pp)
```

so peak ≈ `0.5 + 0.32 ≈ 0.82 A`. The shop's 120 µH part is rated **1 A** —
the 1 A rating exceeds the 0.82 A peak with approximately 20 % margin, so
saturation is not a concern at this load. The 1N5817 (1 A) and the
electrolytics are comfortably within rating.

## 4. LM7812 linear (24 V → 12 V), gate-drive rail

The +12V rail only powers the two-stage BS170 gate-drive (Task 5). A gate driver
draws essentially **no static current** — its average supply current is the
charge needed to swing the heater-MOSFET gate, delivered once per PWM edge:

```
I_avg ≈ Qg · f_pwm
```

For a logic-level / standard power MOSFET `Qg ≈ 60–100 nC`. The heater PWM is
slow (reflow control runs at a few Hz to ~1 kHz; take an upper bound
`f_pwm = 1 kHz`):

```
I_avg ≈ 100 nC × 1 kHz = 0.1 mA   (gate-charge component)
```

Even adding the BS170 stages' bias/leakage and a generous margin, the +12V draw
is only **a few milliamps**. LM7812 dissipation:

```
P_diss = (Vin − Vout) × I_avg = (24 − 12) × ~3 mA ≈ 0.036 W  (< 0.1 W)
```

This is far below the LM7812's ~1 W free-air (no-heatsink) limit, so **no
heatsink is required** on U3. (Even a pessimistic 20 mA load gives
`12 × 0.02 = 0.24 W`, still no-heatsink territory.)

### Support passives (LM7812 datasheet)

| Ref | Value | Role | Shop part |
|-----|---|---|---|
| C3 | **0.33 µF** (330 nF) | Input bypass, +24V→GND at U3.IN | `Capacitor,Film,330n` |
| C4 | **0.1 µF** (100 nF) | Output bypass, +12V→GND at U3.OUT | `Capacitor,Ceramic,100n` |

0.33 µF in / 0.1 µF out are the 78xx-series datasheet-recommended bypass values
(needed for stability when the regulator is far from the bulk caps).

## 5. Input cap ripple-current rating

The buck's input capacitor C1 sees the chopped switch current. Worst-case input
RMS ripple for a buck is bounded by

```
I_C,rms ≈ Iout · √(D · (1 − D)),   D = Vout/Vin = 5/24 ≈ 0.21
        ≈ 0.5 · √(0.21 · 0.79) ≈ 0.5 · 0.41 ≈ 0.20 A(rms)
```

A standard 100 µF / 35 V aluminium electrolytic is rated well above 200 mA
ripple at 100 kHz, so C1's ripple-current rating is **not** the limiting factor
here. (Voltage rating is: the 24 V rail demands a ≥ 35 V can — the 100 µF shop
part must be selected in a ≥ 35 V voltage class.) The 1000 µF output cap C2 sees
only the inductor ripple (~0.63 A pp / √12 ≈ 0.18 A rms), again within a
standard 1000 µF/16 V (or the 50 V shop part) rating.

## 6. PWR_FLAG / ERC note

`+24V` and `GND` are fed only from passive/connector and power-*input* pins, so
each carries a `PWR_FLAG` to declare a driver to ERC. `+5V` and `+12V` are
driven by the regulator **output** pins (`power_out`) and therefore need no
flag. The Task-4 power-net ERC section (`U2`, `U3`, `L1`, `D2`, `D3`, `F1`,
`J1`, `C1`–`C4`) reports **no unconnected / no-driver errors**; remaining ERC
errors belong to the controller and power-stage sections wired in Tasks 5–6.

## 7. Heater power stage + boot-safe gate drive (Task 5)

### 7.1 Topology (non-inverting, boot-safe)

```
HEATER_PWM --R2(1k)--> Q2.G        Q2.S=GND   R1(100k) Q2.G->GND pulldown
Q2.D = GD_NODE1                    R3(10k)    GD_NODE1->+12V pull-UP
GD_NODE1 --> Q3.G                  Q3.S=GND
Q3.D = GATE_MAIN                   R4(10k)    GATE_MAIN->+12V pull-UP
GATE_MAIN --R5(100R)--> Q1.G       R6(10k)    Q1.G->GND gate-source pulldown
Q1.D = HEATER_RET (= J2.2), Q1.S = GND
D4 = SMBJ33A TVS, cathode=HEATER_RET, anode=GND (drain-transient clamp)
```

**Boot-state proof.** GPIO25 (`HEATER_PWM`) floating/low/unpowered →
R1 holds Q2.G low → **Q2 off** → R3 pulls GD_NODE1 to +12 V → **Q3 on** →
Q3 clamps GATE_MAIN to ≈0 V → R5 passes 0 V to Q1.G, and R6 also holds Q1.G
to GND → **Q1 off → heater OFF**. The heater can only turn ON when the GPIO is
actively driven HIGH (Q2 on → GD_NODE1 low → Q3 off → R4 pulls GATE_MAIN to
+12 V → Q1 on). This is inherently fail-safe: no firmware, no GPIO pull, and no
power on the ESP32 is required to keep the heater off. A single inverting stage
is forbidden — it would pull the gate HIGH (heater ON) on a floating boot GPIO.

### 7.2 Q1 (IRFS4710) conduction loss

Heater: 24 V resistive element drawing ~13 A (≈ 1.85 Ω, ~310 W class). The
IRFS4710 is a low-side switch in series with the element, Rds(on) ≈ 14 mΩ
(0.014 Ω) at Vgs = 10 V / Tj = 25 °C (the DTU-shop reason for this part —
lowest Rds(on) available).

```
P_cond = I² · Rds(on) = 13² × 0.014 = 169 × 0.014 ≈ 2.37 W
```

At elevated Tj, Rds(on) rises (≈ 1.4× at 100 °C) so a hot-state worst case is
~3.3 W. A bare TO-220 in still air is ~62 °C/W (junction-to-ambient) — far too
hot for 2.4 W (ΔT ≈ 150 °C). **Q1 therefore requires a heatsink**: with a
clip-on TO-220 heatsink (~20 °C/W) plus the device Rθjc (~1 °C/W) and an
insulating pad (~1–2 °C/W), Tj ≈ Ta + 3.3 W × ~23 °C/W ≈ 25 + 75 ≈ 100 °C —
acceptable, with margin to the 175 °C rating. Use a TO-220 heatsink + thermal
pad. (The heater itself is the real power dissipator; Q1's 2.4 W is the switch
overhead.)

### 7.3 Gate drive — switching time ≪ PWM period

The control loop uses **slow PWM** (LEDC, on the order of 1 kHz or slower; PWM
period ≥ 1 ms). The IRFS4710 gate charge Qg ≈ 150 nC (total, to 10 V). With the
12 V rail through the stage-2 pull-up R4 = 10 kΩ as the dominant turn-ON path:

```
I_charge,avg ≈ V/R = 12 / 10 000 = 1.2 mA  (worst case, pull-up-limited)
t_on ≈ Qg / I = 150e-9 / 1.2e-3 ≈ 125 µs
```

Turn-OFF is faster: Q3 sinks the gate to GND through R5 = 100 Ω
(t_off ≈ Qg·R5/12 ≈ 150e-9·100/12 ... dominated by R5 ≈ a few µs). Even the
slow ~125 µs turn-ON edge is ≪ the ≥ 1 ms PWM period, so switching loss is
negligible relative to the 2.4 W conduction loss, and the edge is well within
one PWM slot. (R4 sizing trades turn-on speed against the +12 V quiescent
current when Q3 is on: 12 V / 10 kΩ = 1.2 mA through R4 — negligible for the
LM7812 rail.)

### 7.4 Vgs verification

- Gate is driven to the **+12 V** rail (GATE_MAIN pulled up by R4 when Q1 is on).
- IRFS4710 Vgs(max) = **±20 V** → 12 V is comfortably inside the safe window
  (60 % of max, headroom for ringing).
- IRFS4710 Vgs(th) ≈ **2–4 V** → 12 V ≫ Vgs(th): the device is **fully
  enhanced**, putting it deep in the ohmic region so the 14 mΩ Rds(on) figure
  applies. Logic-level 3.3 V direct drive would NOT fully enhance it (hence the
  12 V two-stage level shifter).

### 7.5 D4 TVS clamp

D4 = **SMBJ33A** (DTU-shop unidirectional TVS), standoff 33 V, clamping
≈ 53 V. Placed cathode→HEATER_RET, anode→GND it clamps inductive/parasitic
drain transients when Q1 interrupts the heater current. 33 V standoff sits
above the 24 V rail (no conduction in normal operation) and the ≈ 53 V clamp is
well below Q1's Vds(max) = **100 V**, protecting the MOSFET drain.

### 7.6 Resistor values (DTU shop, E24/E96)

| Ref | Value | Role |
|-----|---|---|
| R1 | 100 kΩ | Q2.G → GND pulldown (floating logic input = Q2 off) |
| R2 | 1 kΩ | HEATER_PWM → Q2.G series (limits GPIO current) |
| R3 | 10 kΩ  | GD_NODE1 → +12 V pull-UP (stage-1 load) |
| R4 | 10 kΩ  | GATE_MAIN → +12 V pull-UP (stage-2 load / Q1 turn-on) |
| R5 | 100 Ω  | GATE_MAIN → Q1.G series gate resistor (damps gate ringing) |
| R6 | 10 kΩ  | Q1.G → GND gate-source pulldown (belt-and-suspenders) |

All are standard E24 values stocked in `components-inventory/dtu_component_shop(1).csv`.

## 8. High-current pour width (Task 9 layout requirement)

The heater loop (J2 → element → Q1 drain `HEATER_RET` → Q1 source → `GND`,
and the `+24V` feed to the element) carries the full **13 A** heater current.
On a single-sided laser/mill board this copper is **35 µm (1 oz)** on an
external layer, so the conductor cross-section must be sized by the
**IPC-2221** external-layer formula:

```
A[mil²] = ( I / (k · ΔT^0.44) ) ^ (1/0.725)        k = 0.048 (external layer)
w       = A / (thickness in mil)                    1 oz = 1.378 mil (35 µm)
```

For **I = 13 A** and a **≤ 20 °C** temperature rise:

```
A = (13 / (0.048 · 20^0.44))^(1/0.725) ≈ 368 mil²
w = 368 / 1.378 ≈ 267 mil ≈ 6.8 mm        (ΔT = 20 °C)
```

Sensitivity to the allowed rise (same 13 A, 1 oz, external):

| ΔT rise | Required pour width |
|---:|---:|
| 30 °C | ≈ 5.3 mm |
| **20 °C** | **≈ 6.8 mm** (IPC-2221 minimum) |
| 10 °C | ≈ 10.3 mm |

**Task 9 layout target: make every 13 A conductor a flood pour ≥ 8 mm wide,
aiming for ~10 mm where the board allows.** 6.8 mm is the bare IPC-2221
minimum at ΔT = 20 °C; widening to 8–10 mm pulls the rise toward ~10–15 °C and
covers (a) the etched-edge/under-etch tolerance of the laser process, which
narrows the effective conductor, and (b) the lack of a second copper layer or
thermal vias to spread heat. The high-current nets to size are `+24V` (heater
feed), `HEATER_RET` (Q1 drain), and the heater-return `GND` back to J1/J2.
Lower-current rails (`+5V`, `+12V`, `+3V3`, logic) have no such requirement and
use the default 1.0 mm track.

> Cross-check at layout: measure the narrowest copper on `+24V`, `HEATER_RET`,
> and the heater `GND` return; each must be **≥ 8 mm** (≥ 6.8 mm is the hard
> IPC-2221 floor for ΔT ≤ 20 °C).

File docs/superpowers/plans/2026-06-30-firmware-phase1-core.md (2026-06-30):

# Reflow Firmware — Phase 1: Core Logic Implementation Plan

> **For agentic workers:** REQUIRED SUB-SKILL: Use superpowers:subagent-driven-development (recommended) or superpowers:executing-plans to implement this plan task-by-task. Steps use checkbox (`- [ ]`) syntax for tracking.

**Goal:** Build and unit-test the pure-C control core of the reflow firmware — PID, reflow profile model, run state machine, safety watchdog, and the profile settings store — entirely on the desktop (`native`) with Unity, with zero ESP-IDF dependencies.

**Architecture:** A PlatformIO project with two envs: `esp32dev` (framework=espidf, for later phases) and `native` (gcc + Unity, for these tests). The control core lives in `firmware/lib/core/` as a standalone C library with NO hardware/ESP-IDF includes, so it compiles and is unit-tested on the host. Later phases (HAL, UI, net) link this same library on the ESP32.

**Tech Stack:** PlatformIO 6.1.x, ESP-IDF (target env only, not exercised in this phase), C11, Unity test framework on the `native` platform.

## Global Constraints

- **Language:** C11, pure C. `firmware/lib/core/` must include ONLY the C standard library + its own headers — NO `esp_*`, `driver/*`, `freertos/*`, or Arduino headers (that is what keeps it native-testable). Verified by the `native` build compiling it with gcc.
- **Testing:** `native` env, Unity. Tests live under `firmware/test/`. Run with `pio test -e native`. Every `core/` module is TDD'd: failing Unity test first, then implementation.
- **Safety ceiling:** `SAFETY_CEILING_C = 260` (°C), defined once in `core/safety.h` and used by `profile_validate` and the over-temp trip (spec §4/§7).
- **Default profiles (seed data):** leaded **Sn63/Pb37** and lead-free **SAC305**, as stage tables (spec §2).
- **No hardware in this phase.** No `main.c`, no drivers, no FreeRTOS. Pure logic + tests only.
- **Commits:** never mention Claude/AI in commit messages.

## File Structure

```
firmware/
  platformio.ini            two envs: esp32dev (espidf), native (unity)
  partitions.csv            app + nvs (created now, used in Phase 2)
  lib/core/                 PURE C control library (native-testable)
    pid.h / pid.c           PID controller (struct + step fn)
    profile.h / profile.c   profile/stage model + setpoint interpolation + validation + defaults
    reflow.h / reflow.c      run state machine
    safety.h / safety.c      watchdog verdict + SAFETY_CEILING_C
    settings.h / settings.c  profile store over an injected storage_if (CRUD, seed)
  test/
    test_smoke/test_smoke.c  proves the native+Unity toolchain runs
    test_pid/test_pid.c
    test_profile/test_profile.c
    test_settings/test_settings.c
    test_reflow/test_reflow.c
    test_safety/test_safety.c
  README.md                 build/flash + native test instructions (seeded now)
```

---

### Task 1: PlatformIO scaffold + native Unity toolchain

**Files:**
- Create: `firmware/platformio.ini`, `firmware/partitions.csv`, `firmware/README.md`,
  `firmware/lib/core/.gitkeep`, `firmware/test/test_smoke/test_smoke.c`

**Interfaces:**
- Produces: a working `pio test -e native` that runs Unity on the host.

- [ ] **Step 1: Write `platformio.ini`**

```ini
[env:esp32dev]
platform = espressif32
framework = espidf
board = esp32doit-devkit-v1
board_build.partitions = partitions.csv
monitor_speed = 115200

[env:native]
platform = native
test_framework = unity
build_flags = -std=c11 -Wall -Wextra -I lib/core
```

- [ ] **Step 2: Write `partitions.csv`** (used in Phase 2; harmless now)

```csv
# Name,   Type, SubType, Offset,  Size,    Flags
nvs,      data, nvs,     0x9000,  0x6000,
phy_init, data, phy,     0xf000,  0x1000,
factory,  app,  factory, 0x10000, 0x2C0000,
```

- [ ] **Step 3: Write the smoke test** `firmware/test/test_smoke/test_smoke.c`

```c
#include <unity.h>
void setUp(void) {}
void tearDown(void) {}
static void test_toolchain_runs(void) { TEST_ASSERT_EQUAL_INT(4, 2 + 2); }
int main(void) { UNITY_BEGIN(); RUN_TEST(test_toolchain_runs); return UNITY_END(); }
```

- [ ] **Step 4: Run the native tests — expect PASS**

```bash
cd firmware && pio test -e native
```
Expected: `test_smoke ... PASSED`, 1 test, 0 failures. (If `pio` isn't found, use `python -m platformio test -e native`.)

- [ ] **Step 5: Seed `README.md`** with: project intro, `pio test -e native` (host tests),
  `pio run -e esp32dev` (build firmware, later phases), and the pin map from spec §3.1.

- [ ] **Step 6: Commit**

```bash
git add firmware/platformio.ini firmware/partitions.csv firmware/README.md firmware/lib/core/.gitkeep firmware/test/test_smoke
git commit -m "firmware: PlatformIO scaffold with native Unity test env"
```

---

### Task 2: PID controller (`core/pid`)

**Files:**
- Create: `firmware/lib/core/pid.h`, `firmware/lib/core/pid.c`, `firmware/test/test_pid/test_pid.c`

**Interfaces:**
- Produces:
  ```c
  typedef struct { float kp, ki, kd; float out_min, out_max;
                   float integ; float prev_meas; int started; } pid_t;
  void  pid_init(pid_t *p, float kp, float ki, float kd, float out_min, float out_max);
  void  pid_reset(pid_t *p);
  float pid_step(pid_t *p, float setpoint, float measurement, float dt_s); /* returns clamped output */
  ```
  Output clamped to `[out_min,out_max]`; integral anti-windup (no accumulation while
  saturated); derivative on measurement (`-kd*d(meas)/dt`), not on error.

- [ ] **Step 1: Write failing tests** `test_pid/test_pid.c` — proportional output, integral
  accumulation toward setpoint, anti-windup clamp at `out_max`, and derivative-on-measurement
  (a setpoint jump must NOT produce a derivative spike). Example:

```c
#include <unity.h>
#include "pid.h"
void setUp(void){} void tearDown(void){}
static void test_p_only(void){ pid_t p; pid_init(&p,2,0,0,0,100);
    TEST_ASSERT_FLOAT_WITHIN(0.01f, 20.0f, pid_step(&p,110,100,1.0f)); }   /* 2*(110-100)=20 */
static void test_clamp_and_antiwindup(void){ pid_t p; pid_init(&p,0,10,0,0,100);
    for(int i=0;i<100;i++) pid_step(&p,200,0,1.0f);
    TEST_ASSERT_FLOAT_WITHIN(0.01f,100.0f, pid_step(&p,200,0,1.0f));      /* clamped */
    float integ_sat=p.integ; pid_step(&p,200,0,1.0f);
    TEST_ASSERT_TRUE(p.integ <= integ_sat+0.001f); }                      /* no windup */
static void test_deriv_on_measurement_no_setpoint_kick(void){ pid_t a,b;
    pid_init(&a,0,0,5,-1000,1000); pid_init(&b,0,0,5,-1000,1000);
    pid_step(&a,100,100,1.0f); float kick=pid_step(&a,140,100,1.0f);      /* setpoint jumps, meas steady */
    pid_step(&b,100,100,1.0f); float steady=pid_step(&b,100,100,1.0f);
    TEST_ASSERT_FLOAT_WITHIN(0.01f, steady, kick); }                      /* identical: no kick */
int main(void){ UNITY_BEGIN(); RUN_TEST(test_p_only); RUN_TEST(test_clamp_and_antiwindup);
    RUN_TEST(test_deriv_on_measurement_no_setpoint_kick); return UNITY_END(); }
```

- [ ] **Step 2: Run — expect FAIL** (`pio test -e native -f test_pid`): undefined `pid_*`.

- [ ] **Step 3: Implement `pid.h` + `pid.c`** — the struct/signatures above; in `pid_step`:
  `error=setpoint-meas; P=kp*error; integ += ki*error*dt (only if previous output not
  saturated in the same direction); D = -kd*(meas - prev_meas)/dt (skip on first call);
  out = clamp(P+integ+D, out_min, out_max); prev_meas=meas`.
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

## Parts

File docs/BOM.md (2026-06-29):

# Bill of Materials — ESP32 reflow hotplate

> Generated from `hardware/kicad/reflow.kicad_sch` (the schematic is
> produced by `hardware/kicad/tools/build_schematic.py`). Every
> **board-soldered** line below resolves to a row in the DTU component
> shop catalogue (`components-inventory/dtu_component_shop(1).csv`),
> verified by `hardware/kicad/tools/check_bom_against_shop.py` (exit 0).
> Modules and bring-your-own hardware are listed separately under
> **External / bring-your-own**.

## Board-soldered parts (DTU component shop)

| Ref | Value | Shop Part_Number | Shop category | Description / role | Footprint |
|---|---|---|---|---|---|
| C1 | 100uF | `100µF` | Capacitor / Electrolytic | Buck input bulk cap, +24V->GND (use >=35V can) | `CP_Radial_D8.0mm_P3.50mm` |
| C2 | 1000uF | `1000µF` | Capacitor / Electrolytic | Buck output cap, +5V->GND (>=16V; 50V shop part) | `CP_Radial_D10.0mm_P5.00mm` |
| C3 | 330nF | `330n` | Capacitor / Film | LM7812 input bypass, +24V->GND | `C_Disc_D5.0mm_W2.5mm_P2.50mm` |
| C4 | 100nF | `100n` | Capacitor / Ceramic | LM7812 output bypass, +12V->GND | `C_Disc_D5.0mm_W2.5mm_P2.50mm` |
| C5 | 100nF | `100n` | Capacitor / Ceramic | MAX31855 (J3) VCC decoupling | `C_Disc_D5.0mm_W2.5mm_P2.50mm` |
| C6 | 100nF | `100n` | Capacitor / Ceramic | OLED (J4) VCC decoupling | `C_Disc_D5.0mm_W2.5mm_P2.50mm` |
| C7 | 10nF | `10n` | Capacitor / Ceramic | Encoder A debounce | `C_Disc_D5.0mm_W2.5mm_P2.50mm` |
| C8 | 10nF | `10n` | Capacitor / Ceramic | Encoder B debounce | `C_Disc_D5.0mm_W2.5mm_P2.50mm` |
| D1 | LED 5MM GRØN | `LED 5MM GRØN` | LED / 5mm | Status LED (GPIO4 via R13) | `LED_D5.0mm` |
| D2 | 1N5817 | `1N5817` | Diode / Schottky | Buck catch diode (Schottky) | `D_DO-41_SOD81_P10.16mm_Horizontal` |
| D3 | P6KE24P | `P6KE24P` | Diode / TVS | 24V input-rail TVS clamp | `D_DO-201AD_P15.24mm_Horizontal` |
| D4 | 1.5KE36A | `1.5KE36A` | Diode / TVS Zener | Heater-drain (HEATER_RET) TVS clamp | `D_DO-201AD_P15.24mm_Horizontal` |
| J1 | 2 pol skrueterminal | `2 pol skrueterminal` | Connector / Terminal | 24V input screw terminal | `TerminalBlock_bornier-2_P5.08mm` |
| J2 | 2 pol skrueterminal | `2 pol skrueterminal` | Connector / Terminal | Heater output screw terminal | `TerminalBlock_bornier-2_P5.08mm` |
| L1 | 120uH | `120µ 1A` | Inductor / Through-hole | Buck inductor (switch node -> +5V) | `L_Toroid_Vertical_L26.7mm_W14.0mm_P10.16mm_Pulse_D` |
| Q1 | IRFS4710 | `IRFS4710` | Transistor / N-MOSFET | Heater low-side power MOSFET | `TO-220-3_Vertical_LaserPads` |
| Q2 | BS170 | `BS170` | Transistor / N-MOSFET | Gate-drive stage-1 level shifter (BS170) | `TO-92_Inline_GDS` |
| Q3 | BS170 | `BS170` | Transistor / N-MOSFET | Gate-drive stage-2 level shifter (BS170) | `TO-92_Inline_GDS` |
| R1 | 100k | `100K` | Resistor / E96 Standard | Q2.G -> GND pulldown (boot-safe) | `R_Axial_DIN0207_L6.3mm_D2.5mm_P7.62mm_Horizontal` |
| R2 | 1k | `1K00` | Resistor / E96 Standard | HEATER_PWM -> Q2.G series | `R_Axial_DIN0207_L6.3mm_D2.5mm_P7.62mm_Horizontal` |
| R3 | 10k | `10K0` | Resistor / E96 Standard | GD_NODE1 -> +12V pull-up | `R_Axial_DIN0207_L6.3mm_D2.5mm_P7.62mm_Horizontal` |
| R4 | 10k | `10K0` | Resistor / E96 Standard | GATE_MAIN -> +12V pull-up | `R_Axial_DIN0207_L6.3mm_D2.5mm_P7.62mm_Horizontal` |
| R5 | 100 | `100R` | Resistor / E96 Standard | GATE_MAIN -> Q1.G series gate resistor | `R_Axial_DIN0207_L6.3mm_D2.5mm_P7.62mm_Horizontal` |
| R6 | 10k | `10K0` | Resistor / E96 Standard | Q1.G -> GND gate-source pulldown | `R_Axial_DIN0207_L6.3mm_D2.5mm_P7.62mm_Horizontal` |
| R7 | 3k09 | `3K09` | Resistor / E96 Standard | LM2575-ADJ FB divider top (+5V->VFB) | `R_Axial_DIN0207_L6.3mm_D2.5mm_P7.62mm_Horizontal` |
| R8 | 1k00 | `1K00` | Resistor / E96 Standard | LM2575-ADJ FB divider bottom (VFB->GND) | `R_Axial_DIN0207_L6.3mm_D2.5mm_P7.62mm_Horizontal` |
| R13 | 330 | `330R` | Resistor / E96 Standard | Status-LED current-limit resistor | `R_Axial_DIN0207_L6.3mm_D2.5mm_P7.62mm_Horizontal` |
| SW1 | Rotary 1x12 EYE | `Rotary 1x12 EYE` | Encoder / Rotary | Rotary encoder (UI) | `RotaryEncoder_Alps_EC11E-Switch_Vertical_H20mm` |
| SW2 | Pushbutton | `Pushbutton` | Hardware / Switch | Start push button (UI) | `SW_PUSH_6mm` |
| U2 | LM2575-ADJ | `LM2575` | IC / Linear | 24V->5V buck regulator (LM2575-ADJ + R7/R8 divider) | `TO-220-5_Vertical_LaserPads` |
| U3 | LM7812 | `LM7812` | IC / Voltage Regulator | 24V->12V linear regulator (gate-drive rail) | `TO-220-3_Vertical_LaserPads` |

### Consolidated purchase list (board parts)

| Qty | Shop Part_Number | Category |
|---|---|---|
| 3 | `100n` | Capacitor/Ceramic |
| 3 | `10K0` | Resistor/E96 Standard |
| 2 | `10n` | Capacitor/Ceramic |
| 2 | `1K00` | Resistor/E96 Standard |
| 2 | `2 pol skrueterminal` | Connector/Terminal |
| 2 | `BS170` | Transistor/N-MOSFET |
| 1 | `1.5KE36A` | Diode/TVS Zener |
| 1 | `1000µF` | Capacitor/Electrolytic |
| 1 | `100K` | Resistor/E96 Standard |
| 1 | `100R` | Resistor/E96 Standard |
| 1 | `100µF` | Capacitor/Electrolytic |
| 1 | `120µ 1A` | Inductor/Through-hole |
| 1 | `1N5817` | Diode/Schottky |
| 1 | `330R` | Resistor/E96 Standard |
| 1 | `330n` | Capacitor/Film |
| 1 | `3K09` | Resistor/E96 Standard |
| 1 | `IRFS4710` | Transistor/N-MOSFET |
| 1 | `LED 5MM GRØN` | LED/5mm |
| 1 | `LM2575` | IC/Linear |
| 1 | `LM7812` | IC/Voltage Regulator |
| 1 | `P6KE24P` | Diode/TVS |
| 1 | `Pushbutton` | Hardware/Switch |
| 1 | `Rotary 1x12 EYE` | Encoder/Rotary |

## External / bring-your-own (not board-soldered shop parts)

| Ref | Part | Description | Note |
|---|---|---|---|
| A1 | ESP32-DevKitV1 | 30-pin DOIT ESP32 DevKit V1 controller module | Hand-soldered 2x15 pin-header module (not a discrete shop part) |
| J3 | MAX31855 | MAX31855 K-type thermocouple amplifier breakout + thermocouple | Module on a 1x05 header; thermocouple is bring-your-own |
| J4 | OLED (SSD1306) | 0.96" SSD1306 128x64 I2C OLED module | Module on a 1x04 header |
| F1 | 24V fuse holder + element | 5x20mm cartridge fuse holder, ~15A fuse element | Fuse holder soldered; the fuse element is user-supplied (bring-your-own) |
| PSU | 24V DC supply | External 24V mains PSU feeding J1 | Bring-your-own; sized for the ~310W heater + logic |
| HTR | PTC hotplate element | 24V PTC heating plate wired to J2 | Bring-your-own heating element (~13A) |
| TF | Inline thermal fuse | Series thermal cutoff on the heater feed | Bring-your-own over-temperature safety cutoff |

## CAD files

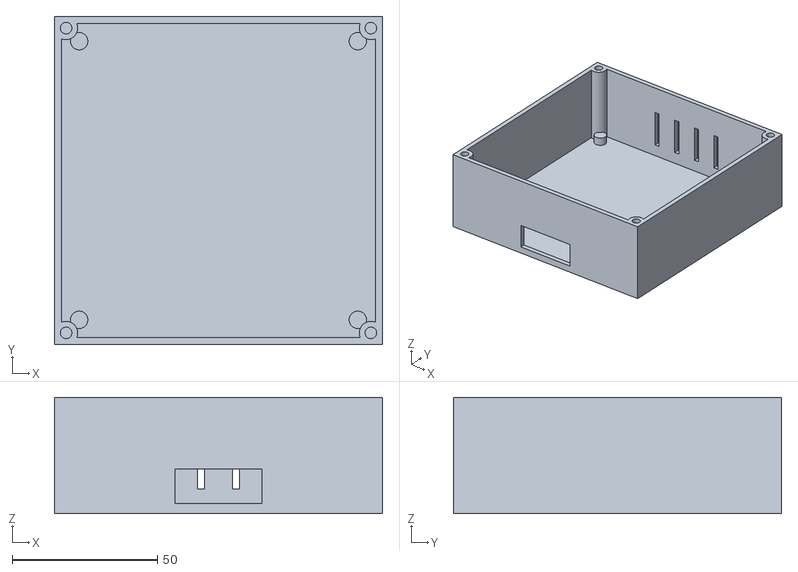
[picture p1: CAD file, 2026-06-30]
hardware/3d/stl/box.stl
113.0 x 113.0 x 40.0

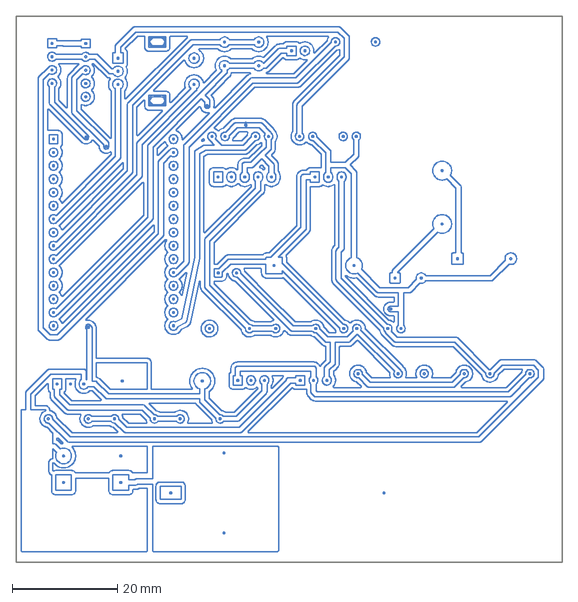
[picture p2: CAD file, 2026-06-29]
hardware/kicad/production/reflow.dxf
104.0 x 104.0 mm

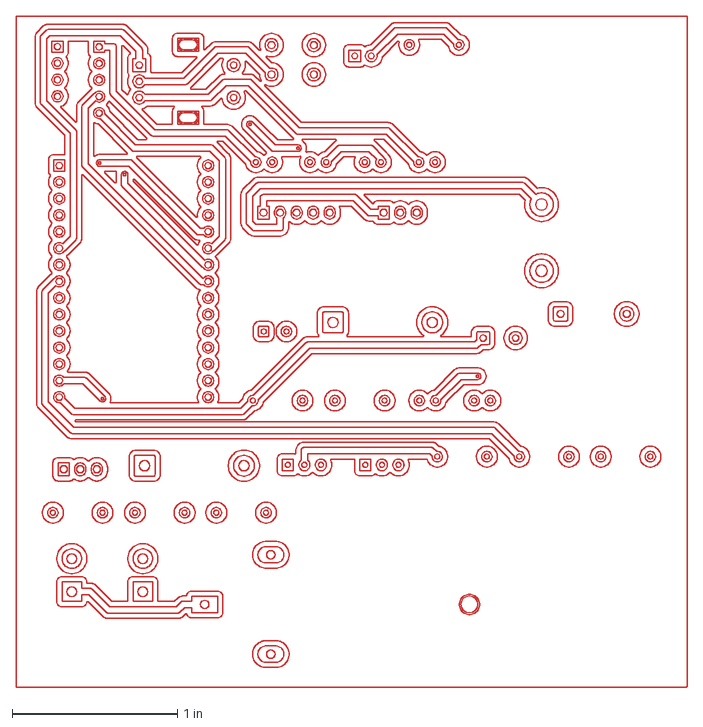
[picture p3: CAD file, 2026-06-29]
hardware/kicad/production/reflow_top_cu.dxf/reflow-F_Cu.dxf
4.06 x 4.06 in

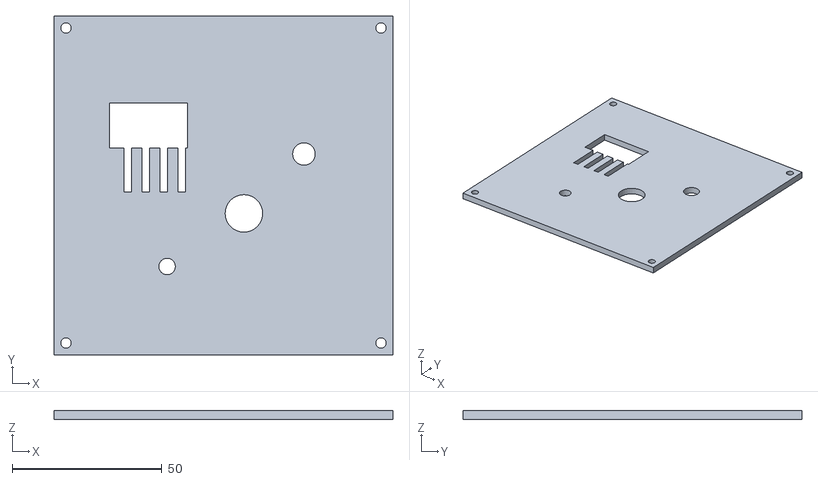
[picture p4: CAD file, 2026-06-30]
hardware/3d/stl/panel.stl
113.0 x 113.0 x 3.00

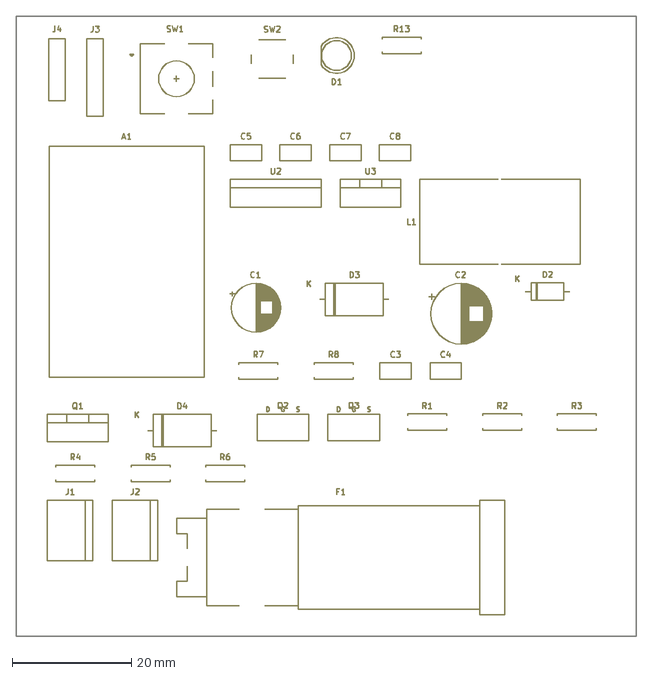
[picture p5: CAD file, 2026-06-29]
hardware/kicad/production/reflow_silk_top.dxf
104.0 x 104.0 mm

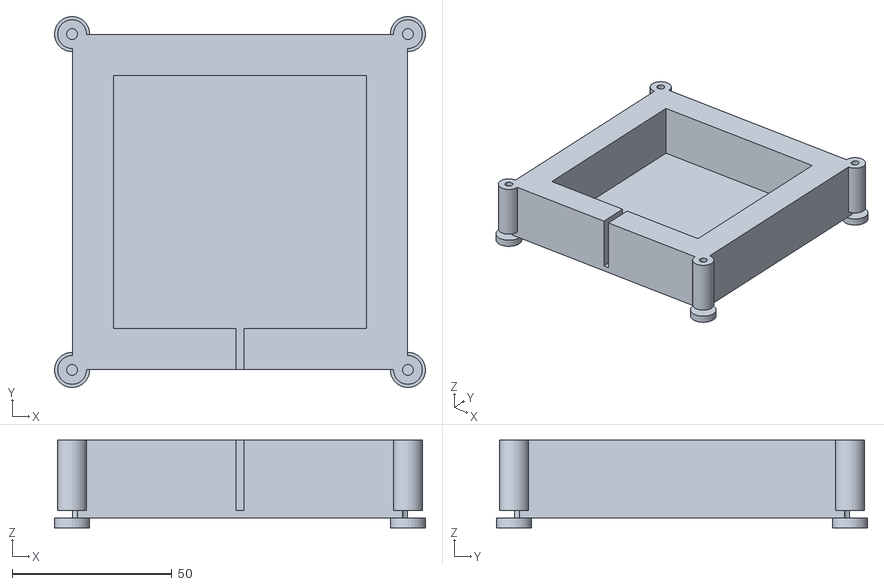
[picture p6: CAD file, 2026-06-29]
hardware/3d/stl/plate_frame.stl
116.0 x 116.0 x 27.4

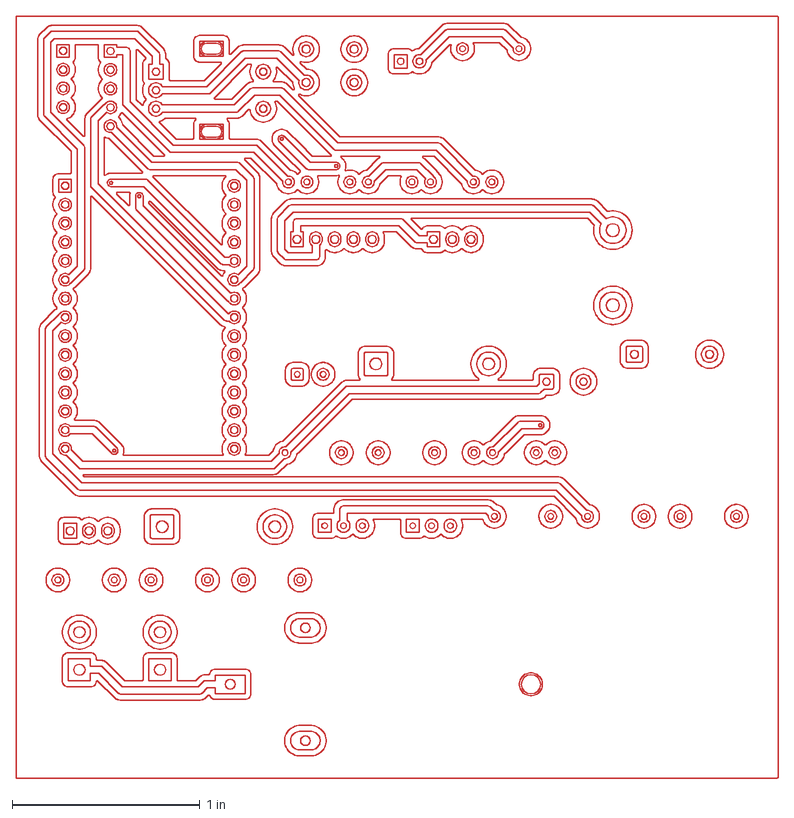
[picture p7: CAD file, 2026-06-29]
hardware/kicad/production/reflow-F_Cu.dxf
4.06 x 4.06 in

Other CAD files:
hardware/3d/enclosure.blend

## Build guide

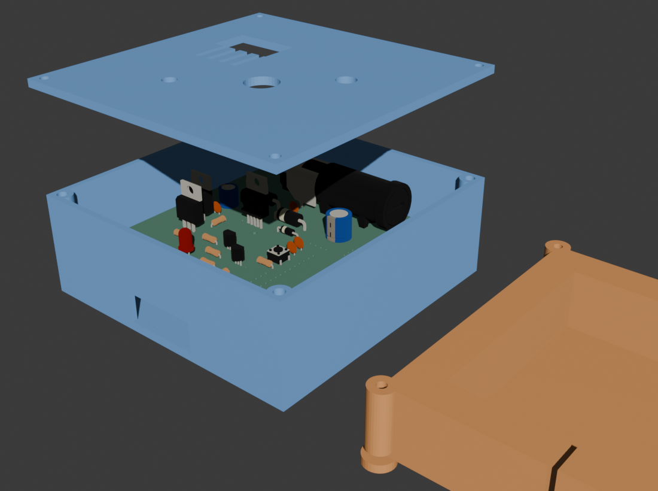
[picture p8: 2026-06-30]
hardware/3d/pcb/assembly_view.png

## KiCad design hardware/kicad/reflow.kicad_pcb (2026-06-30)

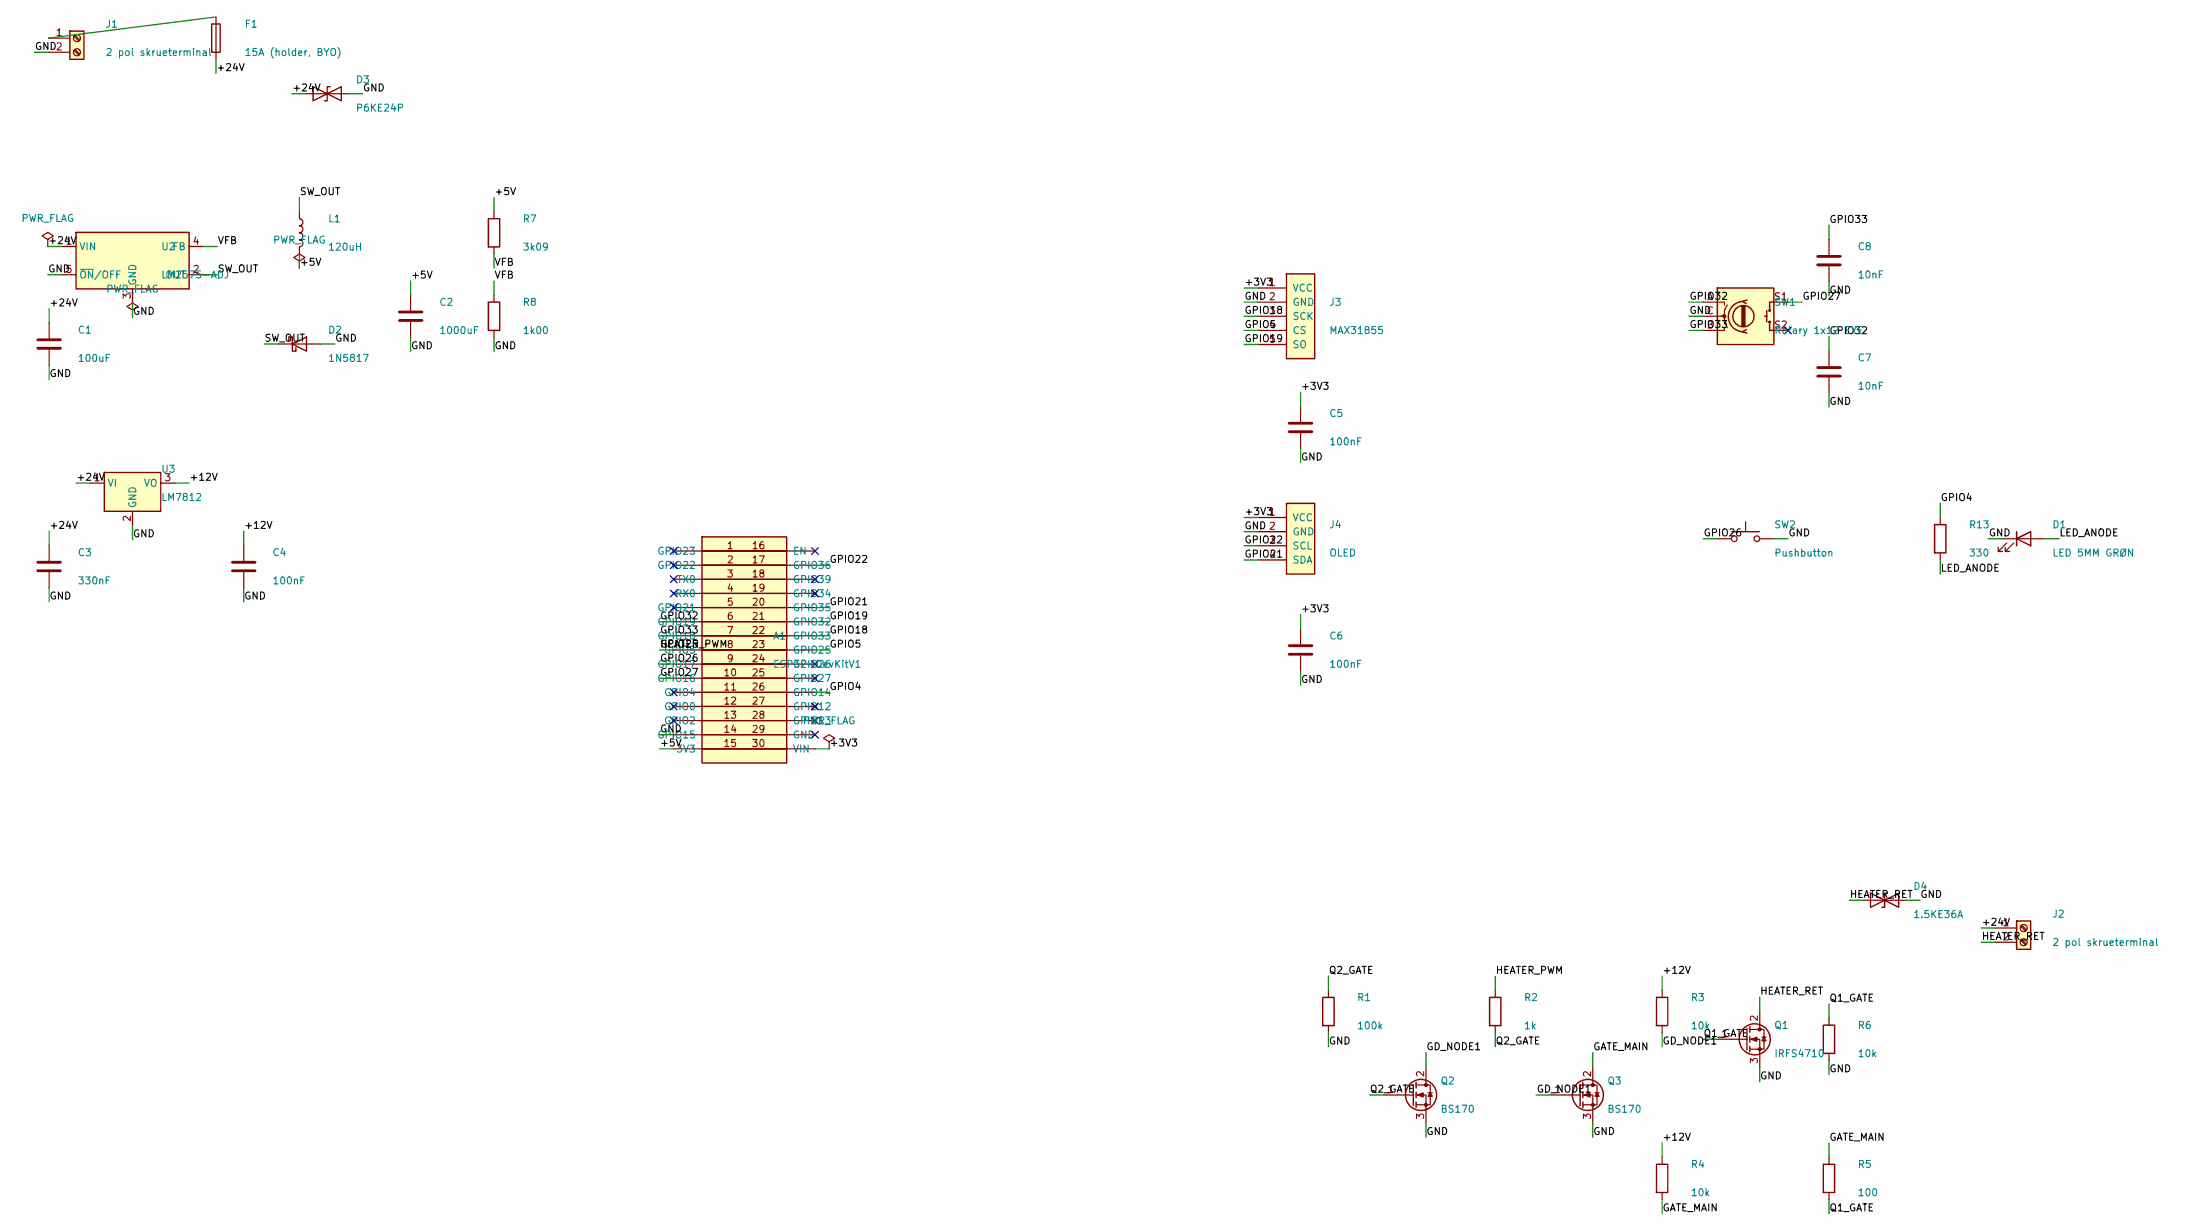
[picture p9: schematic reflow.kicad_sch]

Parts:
A1: ESP32-DevKitV1; ESP32_DevKitV1_2x15_P2.54_W22.86
C1: 100uF; CP_Radial_D8.0mm_P3.50mm
C2: 1000uF; CP_Radial_D10.0mm_P5.00mm
C3: 330nF; C_Disc_D5.0mm_W2.5mm_P2.50mm
C4, C5, C6: 100nF; C_Disc_D5.0mm_W2.5mm_P2.50mm
C7, C8: 10nF; C_Disc_D5.0mm_W2.5mm_P2.50mm
D1: LED 5MM GRØN; LED_D5.0mm
D2: 1N5817; D_DO-41_SOD81_P10.16mm_Horizontal
D3: P6KE24P; D_DO-201AD_P15.24mm_Horizontal
D4: 1.5KE36A; D_DO-201AD_P15.24mm_Horizontal
F1: 15A (holder, BYO); Fuseholder_Cylinder-5x20mm_Schurter_FUP_0031.2510_Horizonta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
J1, J2: 2 pol skrueterminal; TerminalBlock_bornier-2_P5.08mm
J3: MAX31855; Header_1x05_P2.54
J4: OLED; Header_1x04_P2.54
L1: 120uH; L_Toroid_Vertical_L26.7mm_W14.0mm_P10.16mm_Pulse_D
Q1: IRFS4710; TO-220-3_Vertical_LaserPads
Q2, Q3: BS170; TO-92_Inline_GDS
R1: 100k; R_Axial_DIN0207_L6.3mm_D2.5mm_P7.62mm_Horizontal
R2: 1k; R_Axial_DIN0207_L6.3mm_D2.5mm_P7.62mm_Horizontal
R3, R4, R6: 10k; R_Axial_DIN0207_L6.3mm_D2.5mm_P7.62mm_Horizontal
R5: 100; R_Axial_DIN0207_L6.3mm_D2.5mm_P7.62mm_Horizontal
R7: 3k09; R_Axial_DIN0207_L6.3mm_D2.5mm_P7.62mm_Horizontal
R8: 1k00; R_Axial_DIN0207_L6.3mm_D2.5mm_P7.62mm_Horizontal
R13: 330; R_Axial_DIN0207_L6.3mm_D2.5mm_P7.62mm_Horizontal
SW1: Rotary 1x12 EYE; RotaryEncoder_Alps_EC11E-Switch_Vertical_H20mm
SW2: Pushbutton; SW_PUSH_6mm
U2: LM2575-ADJ; TO-220-5_Vertical_LaserPads
U3: LM7812; TO-220-3_Vertical_LaserPads

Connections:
/+3V3: A1.30 (3V3), C5.1, C6.1, J3.1 (VCC), J4.1 (VCC)
/+5V: A1.15 (VIN), C2.1, L1.2, R7.1
/+12V: C4.1, R3.1, R4.1, U3.3 (VO)
/+24V: C1.1, C3.1, D3.1 (A1), F1.2, J2.1, U2.1 (VIN), U3.1 (VI)
/GATE_MAIN: Q3.2 (D), R4.2, R5.1
/GD_NODE1: Q2.2 (D), Q3.1 (G), R3.2
/GND: A1.14 (GND), C1.2, C2.2, C3.2, C4.2, C5.2, C6.2, C7.2, C8.2, D1.1 (K), D2.2 (A), D3.2 (A2), D4.2 (A2), J1.2, J3.2 (GND), J4.2 (GND), Q1.3 (S), Q2.3 (S), Q3.3 (S), R1.2, R6.2, R8.2, SW1.C, SW2.2, U2.3 (GND), U2.5 (~ON/OFF), U3.2 (GND)
/GPIO4: A1.26 (GPIO4), R13.1
/GPIO5: A1.23 (GPIO5), J3.4 (CS)
/GPIO18: A1.22 (GPIO18), J3.3 (SCK)
/GPIO19: A1.21 (GPIO19), J3.5 (SO)
/GPIO21: A1.20 (GPIO21), J4.4 (SDA)
/GPIO22: A1.17 (GPIO22), J4.3 (SCL)
/GPIO25: A1.8 (GPIO25), R2.1
/GPIO26: A1.9 (GPIO26), SW2.1
/GPIO27: A1.10 (GPIO27), SW1.S1
/GPIO32: A1.6 (GPIO32), C7.1, SW1.A
/GPIO33: A1.7 (GPIO33), C8.1, SW1.B
/HEATER_RET: D4.1 (A1), J2.2, Q1.2 (D)
/LED_ANODE: D1.2 (A), R13.2
/Q1_GATE: Q1.1 (G), R5.2, R6.1
/Q2_GATE: Q2.1 (G), R1.1, R2.2
/SW_OUT: D2.1 (K), L1.1, U2.2 (OUT)
/VFB: R7.2, R8.1, U2.4 (FB)
unnamed: F1.1, J1.1

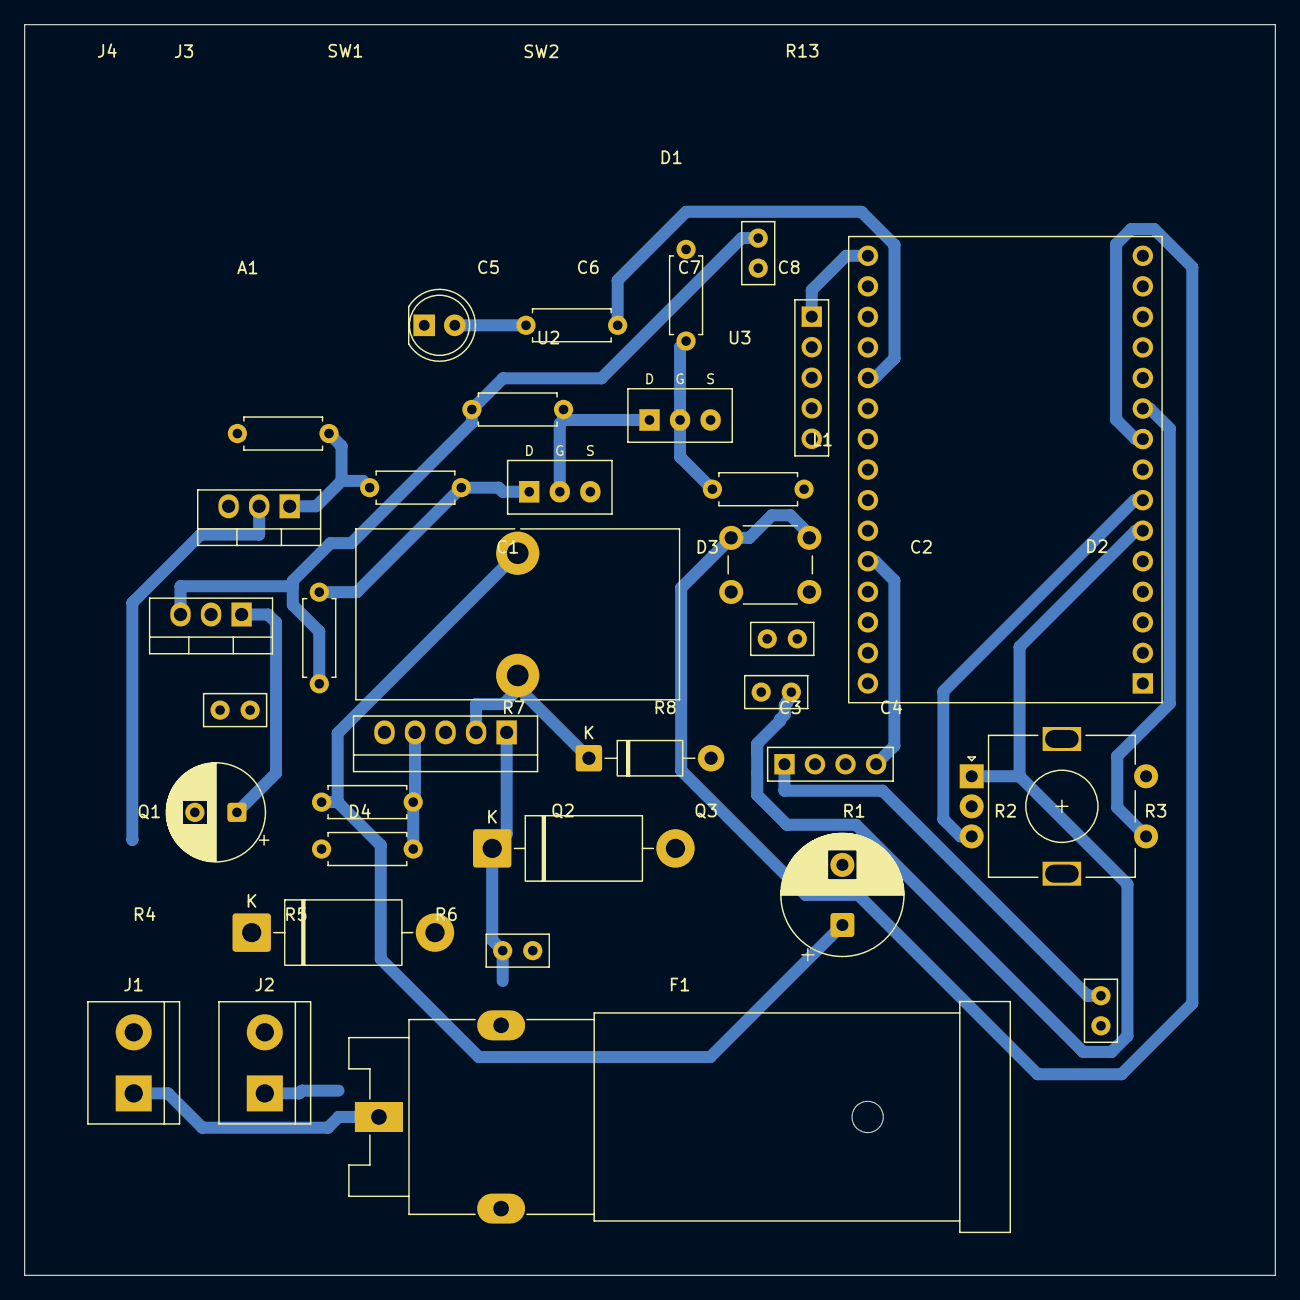
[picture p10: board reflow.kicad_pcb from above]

Board: 2 copper layers, 104.0 x 104.0 mm, 35 parts (0 on the bottom side), 25 nets.

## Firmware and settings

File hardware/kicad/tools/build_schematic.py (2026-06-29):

"""Place all schematic components for the ESP32 reflow hotplate (Task 3).

PLACEMENT ONLY: every component from the design-of-record is emitted as a
KiCad-10 ``(symbol ...)`` block with a fresh UUID. No wires, no net labels,
no power-flag symbols -- those are added in the wiring tasks (4-6).

Reference designators follow ``hardware/kicad/net_contract.json`` (the
authoritative design-of-record). Where the task brief and the contract
disagree, the contract wins:

    contract                       brief said      ->  used here
    SW1 = rotary encoder           RV1             ->  SW1
    SW2 = start push button        SW1             ->  SW2
    D1  = status LED               D3              ->  D1
    (TVS diode, brief D1)          D1              ->  D3  (D1 taken by LED)

The module symbol/footprint library is registered under the nickname
``reflow`` (Task 2), not ``modules``.

The energy_system symbol library is empty (no LM2576/LM7812 symbols), so the
regulators use stock KiCad symbols:
    U2  Regulator_Switching:LM2576T-5   (5-pin TO-220 buck)
    U3  Regulator_Linear:LM7812_TO220   (3-pin TO-220 linear)
There is NO separate 3V3 regulator (3V3 comes from the ESP32 onboard LDO).

KiCad-10 file format (version 20250114, generator_version 10.0); matches the
header that Task 1 wrote into reflow.kicad_sch.
"""

import math
import re
import shutil
import uuid
from datetime import datetime
from pathlib import Path

ROOT = Path(__file__).resolve().parent.parent          # hardware/kicad
SCH = ROOT / "reflow.kicad_sch"
BACKUP = ROOT / f"reflow.kicad_sch.bak_{datetime.now():%Y%m%d_%H%M%S}"

# Source symbol libraries, keyed by lib nickname. Used to (a) populate the
# schematic's (lib_symbols) block with real pin geometry + electrical types
# -- without which ERC/connectivity collapses every pin onto the symbol origin
# -- and (b) compute absolute pin endpoints for the Task-4 power wiring.
KICAD_SYMBOL_DIR = Path(r"C:\Program Files\KiCad\10.0\share\kicad\symbols")
LIB_SOURCES = {
    "Device": KICAD_SYMBOL_DIR / "Device.kicad_sym",
    "Regulator_Switching": KICAD_SYMBOL_DIR / "Regulator_Switching.kicad_sym",
    "Regulator_Linear": KICAD_SYMBOL_DIR / "Regulator_Linear.kicad_sym",
    "Switch": KICAD_SYMBOL_DIR / "Switch.kicad_sym",
    "Connector": KICAD_SYMBOL_DIR / "Connector.kicad_sym",
    "Transistor_FET": KICAD_SYMBOL_DIR / "Transistor_FET.kicad_sym",
    "reflow": ROOT / "modules.kicad_sym",
}

# Project UUID taken from the existing reflow.kicad_sch header.
PROJ_UUID = "a1b2c3d4-0001-0001-0001-000000000001"

# Pin identifiers per lib_id. KiCad requires a (pin "<id>" ...) instance entry
# for every pin of the symbol; the identifier must match the library symbol's
# pin numbers exactly (note RotaryEncoder uses A/B/C/S1/S2, not 1..5).
PIN_IDS = {
    "reflow:ESP32_DevKitV1": [str(i) for i in range(1, 31)],
    "reflow:MAX31855_Module": ["1", "2", "3", "4", "5"],
    "reflow:OLED_SSD1306_I2C": ["1", "2", "3", "4"],
    "Regulator_Switching:LM2575BT-ADJ": ["1", "2", "3", "4", "5"],
    "Regulator_Linear:LM7812_TO220": ["1", "2", "3"],
    "Transistor_FET:Q_NMOS_GDS": ["1", "2", "3"],
    "Device:RotaryEncoder_Switch": ["A", "B", "C", "S1", "S2"],
    "Switch:SW_Push": ["1", "2"],
    "Device:D_TVS": ["1", "2"],
    "Device:D_Schottky": ["1", "2"],
    "Device:LED": ["1", "2"],
    "Device:Fuse": ["1", "2"],
    "Device:L": ["1", "2"],
    "Device:R": ["1", "2"],
    "Device:C": ["1", "2"],
    "Connector:Screw_Terminal_01x02": ["1", "2"],
}

# -----------------------------------------------------------------------------
# Component placement: (ref, lib_id, value, footprint, x, y, angle)
# A3 sheet = 420 x 297 mm. Logical zones:
#   - Controller centre        : A1 ESP32 (~x=150, y=150)
#   - Power section top-left   : J1, F1, D3(TVS), U2 buck + L1/D2, U3 linear
#   - Power corner bottom-right: Q1 heater MOSFET, Q2/Q3 gate-drive, J2 heater
#   - UI right edge            : J3 (MAX31855), J4 (OLED), SW1 enc, SW2 btn, D1 LED
# Decoupling caps / gate-drive R+C placed near their consumers (values TBD in
# wiring tasks).
# -----------------------------------------------------------------------------
COMPONENTS = [
    # ---- Controller (centre) ----
    ("A1", "reflow:ESP32_DevKitV1", "ESP32-DevKitV1",
     "reflow:ESP32_DevKitV1_2x15_P2.54_W22.86", 150, 150, 0),

    # ---- Power input + protection (top-left) ----
    # Symbol lib_id is Connector:Screw_Terminal_01x02 (a real, resolvable 2-pin
    # screw-terminal symbol); the footprint stays the vendored bornier-2 part.
    # Task 3 had used "TerminalBlock:..." as the symbol lib_id, but no such
    # *symbol* library exists (TerminalBlock is a footprint lib only), so the
    # pins were unresolvable and could not be wired -- fixed here in Task 4.
    # J1 value snapped to the DTU shop part (Connector,Terminal,2 pol
    # skrueterminal) for the Task-8 BOM cross-check; footprint unchanged.
    ("J1", "Connector:Screw_Terminal_01x02", "2 pol skrueterminal",
     "TerminalBlock:TerminalBlock_bornier-2_P5.08mm", 30, 40, 0),
    # F1 = the 24 V fuse HOLDER -- a bring-your-own/external part (the fuse
    # element is user-supplied), so its value is informational only and F1 is
    # excluded from the shop cross-check (see check_bom_against_shop EXCLUDE_REFS
    # and the BOM "External / bring-your-own" section).
    ("F1", "Device:Fuse", "15A (holder, BYO)",
     "Fuse:Fuseholder_Cylinder-5x20mm_Schurter_FUP_0031.2510_Horizontal_Closed", 55, 40, 0),
    # D3 = 24 V input-rail TVS, snapped to DTU shop P6KE24P (24 V standoff,
    # ~33 V clamp < the 35 V input caps and < LM2575 Vin max). See calcs §2.
    ("D3", "Device:D_TVS", "P6KE24P",
     "Diode_THT:D_DO-201AD_P15.24mm_Horizontal", 75, 50, 0),

    # ---- 24V -> 5V buck (LM2575-ADJ + feedback divider) (top-left) ----
    # Task 8: the DTU component shop stocks the ADJUSTABLE LM2575 (shop row
    # "IC,Linear,LM2575,Step-Down Adjustable Voltage Switching Regulator"), not
    # the fixed LM2576-5.0. Swapped to LM2575BT-ADJ (KiCad stock symbol; same
    # 5-pin TO-220 pinout 1=Vin 2=Out 3=GND 4=FB 5=ON/OFF as the LM2576T-5) and a
    # +5V feedback divider (R7/R8) sets Vout via Vref=1.23 V. The footprint stays
    # the vendored 5-pin laser-pad part. See docs/electrical-calcs.md §3.
    ("U2", "Regulator_Switching:LM2575BT-ADJ", "LM2575-ADJ",
     "energy_system:TO-220-5_Vertical_LaserPads", 40, 80, 0),
    ("L1", "Device:L", "120uH",
     "Inductor_THT:L_Toroid_Vertical_L26.7mm_W14.0mm_P10.16mm_Pulse_D", 70, 75, 0),
    ("D2", "Device:D_Schottky", "1N5817",
     "Diode_THT:D_DO-41_SOD81_P10.16mm_Horizontal", 70, 95, 0),
    ("C1", "Device:C", "100uF",
     "Capacitor_THT:CP_Radial_D8.0mm_P3.50mm", 25, 95, 0),
    ("C2", "Device:C", "1000uF",
     "Capacitor_THT:CP_Radial_D10.0mm_P5.00mm", 90, 90, 0),

    # ---- LM2575-ADJ feedback divider (Task 8) ----
    # Vout = Vref*(1 + R7/R8), Vref = 1.23 V.  R7 (top) = 3K09, R8 (bot) = 1K00
    # -> Vout = 1.23 * (1 + 3090/1000) = 1.23 * 4.09 = 5.03 V.  Both E96 values
    # are stocked in the DTU shop (3K09, 1K00).  Divider: +5V - R7 - FB - R8 - GND.
    ("R7", "Device:R", "3k09",
     "Resistor_THT:R_Axial_DIN0207_L6.3mm_D2.5mm_P7.62mm_Horizontal", 105, 75, 0),
    ("R8", "Device:R", "1k00",
     "Resistor_THT:R_Axial_DIN0207_L6.3mm_D2.5mm_P7.62mm_Horizontal", 105, 90, 0),

    # ---- 24V -> 12V linear (LM7812) gate-drive rail (left) ----
    ("U3", "Regulator_Linear:LM7812_TO220", "LM7812",
     "energy_system:TO-220-3_Vertical_LaserPads", 40, 120, 0),
    # LM7812 datasheet bypass caps (DTU shop: 330n film / 100n ceramic).
    ("C3", "Device:C", "330nF",
     "Capacitor_THT:C_Disc_D5.0mm_W2.5mm_P2.50mm", 25, 135, 0),
    ("C4", "Device:C", "100nF",
     "Capacitor_THT:C_Disc_D5.0mm_W2.5mm_P2.50mm", 60, 135, 0),

    # ---- Heater power stage (bottom-right corner) ----
    ("Q1", "Transistor_FET:Q_NMOS_GDS", "IRFS4710",
     "energy_system:TO-220-3_Vertical_LaserPads", 330, 220, 0),
    # J2 value snapped to the DTU shop screw-terminal part for the BOM check.
    ("J2", "Connector:Screw_Terminal_01x02", "2 pol skrueterminal",
     "TerminalBlock:TerminalBlock_bornier-2_P5.08mm", 380, 200, 0),

    # ---- Two-stage BS170 boot-safe gate drive (bottom-right) ----
    # Gate-drive resistor roles & values per task-5 brief (R1..R6):
    #   R1 100k  Q2.G->GND pulldown (floating logic input => Q2 off)
    #   R2 1k    HEATER_PWM -> Q2.G series
    #   R3 10k   GD_NODE1 -> +12V pull-UP (Q2 off => GD_NODE1 high => Q3 on)
    #   R4 10k   GATE_MAIN -> +12V pull-UP
    #   R5 100R  GATE_MAIN -> Q1.G series gate resistor
    #   R6 10k   Q1.G -> GND gate-source pulldown (belt-and-suspenders)
    ("Q2", "Transistor_FET:Q_NMOS_GDS", "BS170",
     "energy_system:TO-92_Inline_GDS", 270, 230, 0),
    ("Q3", "Transistor_FET:Q_NMOS_GDS", "BS170",
     "energy_system:TO-92_Inline_GDS", 300, 230, 0),
    ("R1", "Device:R", "100k",
     "Resistor_THT:R_Axial_DIN0207_L6.3mm_D2.5mm_P7.62mm_Horizontal", 255, 215, 0),
    ("R2", "Device:R", "1k",
     "Resistor_THT:R_Axial_DIN0207_L6.3mm_D2.5mm_P7.62mm_Horizontal", 285, 215, 0),
    ("R3", "Device:R", "10k",
     "Resistor_THT:R_Axial_DIN0207_L6.3mm_D2.5mm_P7.62mm_Horizontal", 315, 215, 0),
    ("R4", "Device:R", "10k",
     "Resistor_THT:R_Axial_DIN0207_L6.3mm_D2.5mm_P7.62mm_Horizontal", 315, 245, 0),
    ("R5", "Device:R", "100",
     "Resistor_THT:R_Axial_DIN0207_L6.3mm_D2.5mm_P7.62mm_Horizontal", 345, 245, 0),
    ("R6", "Device:R", "10k",
     "Resistor_THT:R_Axial_DIN0207_L6.3mm_D2.5mm_P7.62mm_Horizontal", 345, 220, 0),

    # ---- Heater-drain TVS clamp (Task 5; D4) ----
    # SMBJ33A-equivalent THT TVS across HEATER_RET -> GND (cathode at
    # HEATER_RET, anode at GND) to clamp inductive drain transients when Q1
    # switches the heater load. 33 V standoff sits above the 24 V rail with
    # margin and below Q1's Vds(max)=100 V.
    # D4 snapped to DTU shop 1.5KE36A (36 V standoff > 24 V rail -> no
    # conduction in normal off-state; ~52 V clamp << Q1 Vds(max)=100 V). See §7.5.
    ("D4", "Device:D_TVS", "1.5KE36A",
     "Diode_THT:D_DO-201AD_P15.24mm_Horizontal", 355, 195, 0),

    # ---- Thermocouple header (UI / right) ----
    ("J3", "reflow:MAX31855_Module", "MAX31855",
     "reflow:Header_1x05_P2.54", 250, 90, 0),

    # ---- OLED header (UI / right) ----
    ("J4", "reflow:OLED_SSD1306_I2C", "OLED",
     "reflow:Header_1x04_P2.54", 250, 130, 0),

    # ---- Rotary encoder + start button + status LED (UI / right edge) ----
    # SW1/SW2/D1 values snapped to DTU shop parts for the Task-8 BOM check:
    #   SW1 -> Encoder,Rotary,Rotary 1x12 EYE   SW2 -> Hardware,Switch,Pushbutton
    #   D1  -> LED,5mm,LED 5MM GRØN (green status LED)
    ("SW1", "Device:RotaryEncoder_Switch", "Rotary 1x12 EYE",
     "Rotary_Encoder:RotaryEncoder_Alps_EC11E-Switch_Vertical_H20mm", 330, 90, 0),
    ("SW2", "Switch:SW_Push", "Pushbutton",
     "Button_Switch_THT:SW_PUSH_6mm", 330, 130, 0),
    ("D1", "Device:LED", "LED 5MM GRØN",
     "LED_THT:LED_D5.0mm", 380, 130, 0),
    # R13 = status-LED current-limit resistor (was R6 in Task-3 placement; R6 is
    # reassigned to the gate-drive pulldown per the Task-5 brief). Wired in Task 6.
    ("R13", "Device:R", "330",
     "Resistor_THT:R_Axial_DIN0207_L6.3mm_D2.5mm_P7.62mm_Horizontal", 365, 130, 0),

    # ---- Decoupling + encoder debounce caps (Task 6) ----
    # NOTE (Task 6): R7-R12 were orphaned placeholder resistors from the Task-3
    # generic pool (intended as I2C pull-ups / encoder-button pull-ups). They are
    # NOT used by this design -- the SSD1306 OLED module carries its own I2C
    # pull-ups, and the encoder/start-button use the ESP32 internal pull-ups.
    # They have been removed so they do not appear as floating parts. The
    # resistor set is now exactly R1-R6 (gate drive) + R13 (LED).
    #
    # C5 100nF = J3 (MAX31855) VCC->GND decoupling.
    # C6 100nF = J4 (OLED) VCC->GND decoupling.
    # C7 10nF  = encoder A (SW1.A)->GND debounce.
    # C8 10nF  = encoder B (SW1.B)->GND debounce.
    ("C5", "Device:C", "100nF",
     "Capacitor_THT:C_Disc_D5.0mm_W2.5mm_P2.50mm", 250, 110, 0),
    ("C6", "Device:C", "100nF",
     "Capacitor_THT:C_Disc_D5.0mm_W2.5mm_P2.50mm", 250, 150, 0),
    ("C7", "Device:C", "10nF",
     "Capacitor_THT:C_Disc_D5.0mm_W2.5mm_P2.50mm", 345, 100, 0),
    ("C8", "Device:C", "10nF",
     "Capacitor_THT:C_Disc_D5.0mm_W2.5mm_P2.50mm", 345, 80, 0),
]


def uid() -> str:
    return str(uuid.uuid4())


def pin_ids(lib_id: str):
    if lib_id not in PIN_IDS:
        raise SystemExit(f"Unknown lib_id (no pin map): {lib_id}")
    return PIN_IDS[lib_id]


def render_symbol(ref, lib_id, value, footprint, x, y, angle) -> str:
    pin_block = "\n".join(
        f'\t\t(pin "{p}" (uuid "{uid()}"))' for p in pin_ids(lib_id)
    )
    return f'''\t(symbol
\t\t(lib_id "{lib_id}")
\t\t(at {x} {y} {angle})
\t\t(unit 1)
\t\t(exclude_from_sim no)
\t\t(in_bom yes)
\t\t(on_board yes)
\t\t(dnp no)
\t\t(fields_autoplaced yes)
\t\t(uuid "{uid()}")
\t\t(property "Reference" "{ref}"
\t\t\t(at {x + 5.08} {y - 2.54} 0)
\t\t\t(effects
\t\t\t\t(font
\t\t\t\t\t(size 1.27 1.27)
\t\t\t\t)
\t\t\t\t(justify left)
\t\t\t)
\t\t)
\t\t(property "Value" "{value}"
\t\t\t(at {x + 5.08} {y + 2.54} 0)
\t\t\t(effects
\t\t\t\t(font
\t\t\t\t\t(size 1.27 1.27)
\t\t\t\t)
\t\t\t\t(justify left)
\t\t\t)
\t\t)
\t\t(property "Footprint" "{footprint}"
\t\t\t(at {x} {y} 0)
\t\t\t(effects
\t\t\t\t(font
\t\t\t\t\t(size 1.27 1.27)
\t\t\t\t)
\t\t\t\t(hide yes)
\t\t\t)
\t\t)
\t\t(property "Datasheet" "~"
\t\t\t(at {x} {y} 0)
\t\t\t(effects
\t\t\t\t(font
\t\t\t\t\t(size 1.27 1.27)
\t\t\t\t)
\t\t\t\t(hide yes)
\t\t\t)
\t\t)
\t\t(property "Description" ""
\t\t\t(at {x} {y} 0)
\t\t\t(effects
\t\t\t\t(font
\t\t\t\t\t(size 1.27 1.27)
\t\t\t\t)
\t\t\t\t(hide yes)
\t\t\t)
\t\t)
{pin_block}
\t\t(instances
\t\t\t(project "reflow"
\t\t\t\t(path "/{PROJ_UUID}"
\t\t\t\t\t(reference "{ref}")
\t\t\t\t\t(unit 1)
\t\t\t\t)
\t\t\t)
\t\t)
\t)'''


# =============================================================================
# Task 4: lib_symbols population + power-net wiring
# =============================================================================
#
# Why lib_symbols must be populated: KiCad resolves pin *positions* and pin
# *electrical types* from the (lib_symbols ...) cache embedded in the .kicad_sch.
# With an empty (lib_symbols) every pin collapses onto the symbol origin and is
# typed "[???, ?]" -- ERC then cannot tell rails apart and net labels cannot
# bind to real pin endpoints (the classic silent-no-net trap). We therefore
# copy each used library symbol body into the cache, resolving `extends`.

_LIB_TEXT_CACHE: dict[str, str] = {}


def _lib_text(lib: str) -> str:
    if lib not in _LIB_TEXT_CACHE:
        _LIB_TEXT_CACHE[lib] = LIB_SOURCES[lib].read_text(encoding="utf-8")
    return _LIB_TEXT_CACHE[lib]


def _find_symbol_block(text: str, name: str) -> str | None:
    """Return the balanced ``(symbol "name" ...)`` s-expression, or None."""
    idx = text.find(f'(symbol "{name}"')
    if idx == -1:
        return None
    depth = 0
    for i in range(idx, len(text)):
        c = text[i]
        if c == "(":
            depth += 1
        elif c == ")":
            depth -= 1
            if depth == 0:
                return text[idx:i + 1]
    return None


def lib_symbol_body(lib: str, name: str) -> str:
    """Self-contained ``(symbol "name" ...)`` body for the lib_symbols cache.

    Resolves ``(extends "parent")`` by splicing the parent's graphic/pin
    sub-symbol units (renamed to the child) onto the child's own properties.
    """
    text = _lib_text(lib)
    block = _find_symbol_block(text, name)
    if block is None:
        raise SystemExit(f"symbol not found: {lib}:{name}")
    m = re.search(r'\(extends\s+"([^"]+)"\)', block)
    if not m:
        return block
    parent = m.group(1)
    pblock = _find_symbol_block(text, parent)
    if pblock is None:
        raise SystemExit(f"parent symbol not found: {lib}:{parent}")
    child_inner = block[block.index(f'"{name}"') + len(name) + 2: block.rindex(")")]
    child_inner = re.sub(r'\s*\(extends\s+"[^"]+"\)', "", child_inner, count=1)
    units = re.findall(
        r'\(symbol\s+"' + re.escape(parent) + r'_\d+_\d+".*?\n\t\t\)',
        pblock, re.DOTALL,
    )
    units = [u.replace(f'"{parent}_', f'"{name}_') for u in units]
    return (
        f'(symbol "{name}"\n'
        + child_inner.rstrip()
        + "\n"
        + "\n".join("\t\t" + u for u in units)
        + "\n\t)"
    )


def parse_pins(lib: str, name: str) -> list[dict]:
    """Pin geometry (number, electrical type, local x/y) -- extends-resolved."""
    text = _lib_text(lib)
    block = _find_symbol_block(text, name)
    m = re.search(r'\(extends\s+"([^"]+)"\)', block) if block else None
    geom = _find_symbol_block(text, m.group(1)) if m else block
    out: list[dict] = []
    i = 0
    while True:
        j = geom.find("(pin ", i)
        if j == -1:
            break
        depth = 0
        k = j
        while k < len(geom):
            if geom[k] == "(":
                depth += 1
            elif geom[k] == ")":
                depth -= 1
                if depth == 0:
                    break
            k += 1
        b = geom[j:k + 1]
        i = k + 1
        head = re.match(r"\(pin\s+(\w+)\s+(\w+)", b)
        at = re.search(r"\(at\s+([-\d.]+)\s+([-\d.]+)\s+([-\d.]+)\)", b)
        num = re.search(r'\(number\s+"([^"]+)"', b)
        if head and at:
            out.append(dict(num=num.group(1) if num else "?", etype=head.group(1),
                            x=float(at.group(1)), y=float(at.group(2)),
                            ang=float(at.group(3))))
    return out


def pin_endpoint(px, py, sx, sy, sangle):
    """Absolute schematic coords of a pin's connection point.

    Symbol-local Y is up while schematic Y is down, so local Y is negated;
    the result is then rotated by the placement angle and translated to the
    component origin.
    """
    lx, ly = px, -py
    a = math.radians(sangle)
    rx = lx * math.cos(a) - ly * math.sin(a)
    ry = lx * math.sin(a) + ly * math.cos(a)
    return round(sx + rx, 4), round(sy + ry, 4)


# Placement lookup: ref -> (lib_id, x, y, angle), built from COMPONENTS.
PLACEMENT = {c[0]: (c[1], c[4], c[5], c[6]) for c in COMPONENTS}


def endpoint_of(ref: str, pin_num: str):
    """Absolute (x, y) of ``ref`` pin ``pin_num`` using its placed geometry."""
    lib_id, x, y, ang = PLACEMENT[ref]
    lib, name = lib_id.split(":", 1)
    for p in parse_pins(lib, name):
        if p["num"] == pin_num:
            return pin_endpoint(p["x"], p["y"], x, y, ang)
    raise SystemExit(f"pin {pin_num} not found on {ref} ({lib_id})")


def pin_outward(ref: str, pin_num: str):
    """Unit (dx, dy) in schematic space pointing away from the symbol body
    (the direction a wire should leave the pin). Used to route stubs so they
    never collide with an adjacent pin of the same component."""
    lib_id, _x, _y, sang = PLACEMENT[ref]
    lib, name = lib_id.split(":", 1)
    pin = next(p for p in parse_pins(lib, name) if p["num"] == pin_num)
    # In .kicad_sym a pin's (at .. ang) points outward from the body. The pin
    # body extends in (ang+180); so the *outward* direction the wire leaves is
    # (ang+180) in local space. Apply the Y-flip + placement rotation.
    a = math.radians(pin["ang"] + 180)
    lx, ly = math.cos(a), -math.sin(a)            # local outward, Y flipped
    sa = math.radians(sang)
    dx = lx * math.cos(sa) - ly * math.sin(sa)
    dy = lx * math.sin(sa) + ly * math.cos(sa)
    # snap to the dominant axis (pins are always axis-aligned)
    if abs(dx) >= abs(dy):
        return (1.0 if dx > 0 else -1.0), 0.0
    return 0.0, (1.0 if dy > 0 else -1.0)
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

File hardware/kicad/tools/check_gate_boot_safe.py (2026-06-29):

"""Boot-safety assertion for the IRFS4710 two-stage gate drive (Task 5).

The heater MOSFET (Q1) MUST be OFF whenever the ESP32 GPIO that drives
``HEATER_PWM`` is low, floating, mid-reset, or unpowered. The only topology
that guarantees this *inherently* (no firmware, no external pull on the GPIO
required) is the NON-inverting two-stage BS170 level shifter:

    HEATER_PWM --R2--> Q2.G        (Q2.S=GND, R1 100k pulldown on Q2.G)
    Q2.D = GD_NODE1, R3 pull-UP GD_NODE1 -> +12V
    GD_NODE1 --> Q3.G              (Q3.S=GND)
    Q3.D = GATE_MAIN, R4 pull-UP GATE_MAIN -> +12V
    GATE_MAIN --R5--> Q1.G, R6 pulldown Q1.G -> GND
    Q1.D = HEATER_RET, Q1.S = GND

Boot proof (GPIO floating/low): R1 holds Q2.G low -> Q2 OFF -> R3 pulls
GD_NODE1 to +12V -> Q3 ON -> Q3 clamps GATE_MAIN to GND -> Q1 OFF. R6 is the
belt-and-suspenders gate-source pulldown.

A SINGLE inverting stage (HEATER_PWM pulled up to the gate via a resistor to
+12V, one transistor) is FORBIDDEN: when the GPIO floats at boot the gate is
pulled HIGH and the heater turns ON. This script exits non-zero if that
pattern is present, or if the boot-safe guarantees are missing.

The script consumes the KiCad s-expression netlist exported by:

    kicad-cli sch export netlist --format kicadsexpr -o <out> reflow.kicad_sch

It re-exports automatically if a netlist path is not supplied.
"""

from __future__ import annotations

import re
import subprocess
import sys
import tempfile
from pathlib import Path

ROOT = Path(__file__).resolve().parent.parent          # hardware/kicad
SCH = ROOT / "reflow.kicad_sch"
KICAD_CLI = Path(r"C:\Program Files\KiCad\10.0\bin\kicad-cli.exe")

# Q_NMOS_GDS pin-number -> terminal. Confirmed from the library symbol geometry
# (pin 1 = Gate/input, pin 2 = Drain, pin 3 = Source).
MOSFET = {"1": "G", "2": "D", "3": "S"}


# ---------------------------------------------------------------------------
# Minimal s-expression parse of the (nets ...) block: net-name -> set of
# (ref, pin) nodes. Also harvest component values from the netlist's
# (components ...) block so we can check resistor values.
# ---------------------------------------------------------------------------
def export_netlist() -> str:
    tmp = Path(tempfile.gettempdir()) / "_reflow_bootsafe.net"
    subprocess.run(
        [str(KICAD_CLI), "sch", "export", "netlist",
         "--format", "kicadsexpr", "-o", str(tmp), str(SCH)],
        check=True, capture_output=True, text=True,
    )
    return tmp.read_text(encoding="utf-8")


def parse_nets(text: str) -> dict[str, set[tuple[str, str]]]:
    nets: dict[str, set[tuple[str, str]]] = {}
    # Each (net (code ..) (name "..") ... (node (ref "..")(pin "..")) ...)
    for nm in re.finditer(r'\(net\b(.*?)(?=\(net\b|\Z)', text, re.DOTALL):
        body = nm.group(1)
        name_m = re.search(r'\(name\s+"([^"]*)"', body)
        if not name_m:
            continue
        name = name_m.group(1).lstrip("/")
        nodes = set()
        for node in re.finditer(
            r'\(node\s+\(ref\s+"([^"]+)"\)\s*\(pin\s+"([^"]+)"\)', body
        ):
            nodes.add((node.group(1), node.group(2)))
        nets[name] = nodes
    return nets


def parse_values(text: str) -> dict[str, str]:
    vals: dict[str, str] = {}
    for c in re.finditer(
        r'\(comp\s+\(ref\s+"([^"]+)"\)\s*\(value\s+"([^"]*)"\)', text
    ):
        vals[c[1]] = c[2]
    return vals


def node_net(nets, ref, pin) -> str | None:
    for name, nodes in nets.items():
        if (ref, pin) in nodes:
            return name
    return None


def fail(msg: str) -> None:
    print(f"BOOT-SAFETY FAIL: {msg}")
    sys.exit(1)


def main() -> None:
    if len(sys.argv) > 1:
        text = Path(sys.argv[1]).read_text(encoding="utf-8")
    else:
        text = export_netlist()

    nets = parse_nets(text)
    vals = parse_values(text)

    # Resolve the key nets by the pins that define them (topology, not names).
    q1_g = node_net(nets, "Q1", "1")   # Q1 gate
    q1_d = node_net(nets, "Q1", "2")   # Q1 drain -> HEATER_RET
    q1_s = node_net(nets, "Q1", "3")   # Q1 source -> GND
    q2_g = node_net(nets, "Q2", "1")
    q2_d = node_net(nets, "Q2", "2")   # -> GD_NODE1
    q2_s = node_net(nets, "Q2", "3")
    q3_g = node_net(nets, "Q3", "1")   # = GD_NODE1
    q3_d = node_net(nets, "Q3", "2")   # -> GATE_MAIN
    q3_s = node_net(nets, "Q3", "3")

    for label, val in [("Q1.G", q1_g), ("Q1.D", q1_d), ("Q1.S", q1_s),
                       ("Q2.G", q2_g), ("Q2.D", q2_d), ("Q2.S", q2_s),
                       ("Q3.G", q3_g), ("Q3.D", q3_d), ("Q3.S", q3_s)]:
        if val is None:
            fail(f"{label} is not connected to any net (gate stage unwired).")

    gnd = "GND"
    v12 = "+12V"

    # ---- Sources of both BS170 stages must be GND (low-side inverters). ----
    if q2_s != gnd:
        fail(f"Q2 source is on '{q2_s}', expected GND.")
    if q3_s != gnd:
        fail(f"Q3 source is on '{q3_s}', expected GND.")
    if q1_s != gnd:
        fail(f"Q1 source is on '{q1_s}', expected GND.")

    # ---- Stage chain: Q2.D == Q3.G (the GD_NODE1 inter-stage node). ----
    if q2_d != q3_g:
        fail(f"Inter-stage broken: Q2.D='{q2_d}' must equal Q3.G='{q3_g}' "
             f"(GD_NODE1).")
    gd_node1 = q2_d
    gate_main = q3_d

    # ---- (b) Pull-UP to +12V on GD_NODE1 (R3) and on GATE_MAIN (R4). ----
    def pullup_to_12v(net_name) -> tuple[str, str] | None:
        """Return (ref,otherpin) of a resistor bridging net_name and +12V."""
        v12_nodes = nets.get(v12, set())
        net_nodes = nets.get(net_name, set())
        v12_refs = {r for r, _ in v12_nodes}
        for ref, pin in net_nodes:
            if ref.startswith("R") and ref in v12_refs:
                return ref, pin
        return None

    if pullup_to_12v(gd_node1) is None:
        fail(f"No pull-UP resistor from GD_NODE1 ('{gd_node1}') to +12V "
             f"(R3 missing). Q2-off would not pull GD_NODE1 high -> Q3 would "
             f"not turn on -> Q1 not held off at boot.")
    if pullup_to_12v(gate_main) is None:
        fail(f"No pull-UP resistor from GATE_MAIN ('{gate_main}') to +12V "
             f"(R4 missing).")

    # ---- (a) R6 gate-source pulldown: a resistor Q1.G -> GND. ----
    gnd_refs = {r for r, _ in nets.get(gnd, set())}
    q1g_nodes = nets.get(q1_g, set())
    pulldown = None
    for ref, pin in q1g_nodes:
        if ref.startswith("R") and ref in gnd_refs:
            pulldown = ref
            break
    if pulldown is None:
        fail(f"No gate-source pulldown resistor from Q1.G ('{q1_g}') to GND "
             f"(R6 missing). Q1 gate could float high.")
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

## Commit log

2026-06-29 Initialize ESP32 reflow hotplate project repo
2026-06-29 Spec: boot-safe non-inverting gate drive + ESP32 pin map
2026-06-29 Add hardware (schematic + board) implementation plan
2026-06-29 hardware: KiCad 10 project skeleton + vendored footprint/symbol libs
    [reflow.kicad_sch]
2026-06-29 hardware: net contract, pin map, and module symbols/footprints
2026-06-29 hardware: reconcile net contract power tree (drop phantom 3V3 LDO, U2/U3 regs, interface-level GATEDRV block)
2026-06-29 hardware: place all schematic components
    [reflow.kicad_sch]
2026-06-29 hardware: fix MOSFET lib_id to Device:Q_NMOS_GDS; add U2 footprint TODO
    Change Q1/Q2/Q3 lib_id from Transistor_FET:Q_NMOS_GDS to Device:Q_NMOS_GDS
    (standard KiCad 10 location) in both the PIN_IDS map and COMPONENTS list.
    Add inline TODO on U2 noting the 5-pin LM2576 needs a TO-220-5 laser-pad
    footprint variant before board layout.
    Regenerated reflow.kicad_sch: 37 components, placement check MISSING [],
    kicad-cli export exits 0 with no unresolved-symbol warnings,
    Transistor_FET:Q_NMOS_GDS count=0, Device:Q_NMOS_GDS count=3.
    [reflow.kicad_sch]
2026-06-29 hardware: wire 24V input protection, LM2576 5V, LM7812 12V rails
    [reflow.kicad_sch]
2026-06-29 hw(buck): swap L1 to 120uH 1A to clear peak-current margin
    The 100uH/0.66A shop inductor was below the calculated LM2576 peak
    inductor current (~0.82-0.88A at 0.5A load). Replace with the DTU
    shop 120uH/1A part: 1A rating exceeds the 0.82A peak with ~20% margin
    and reduces ripple from ~0.76A(pp) to ~0.63A(pp).
    Update electrical-calcs.md with recomputed ripple (0.63A pp) and peak
    (0.82A) for L=120uH, and confirm 1A rating provides adequate margin.
    [reflow.kicad_sch]
2026-06-29 hardware: wire IRFS4710 power stage with boot-safe two-stage gate drive
    Add NETS_POWERSTAGE wiring pass: two-stage non-inverting BS170 level
    shifter (Q2/Q3) driving the IRFS4710 (Q1) low-side heater switch.
    - R1 100k Q2.G->GND pulldown, R2 1k HEATER_PWM->Q2.G series
    - R3 10k GD_NODE1->+12V pull-up, R4 10k GATE_MAIN->+12V pull-up
    - R5 100R series gate resistor, R6 10k Q1.G->GND gate-source pulldown
    - HEATER_RET = J2.2 = Q1.D; D4 SMBJ33A TVS clamps drain transients
    - Reassign R6 to the gate pulldown (per brief); status-LED resistor -> R13
    Boot-safe: floating/low GPIO -> Q2 off -> GD_NODE1=+12V -> Q3 on ->
    GATE_MAIN=0V -> Q1 off (heater inherently OFF). Add check_gate_boot_safe.py
    asserting t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
    [reflow.kicad_sch]
2026-06-29 hardware: wire ESP32, MAX31855 SPI, OLED I2C, encoder, button, status LED
    Add NETS_CTRL pass realising every pinmap GPIO on the ESP32 pins plus the
    J3/J4/SW1/SW2/D1 peripherals and their decoupling/debounce caps. Remove the
    orphaned R7-R12 placeholders (encoder/button use internal pull-ups; OLED has
    its own I2C pull-ups) so the resistor set is R1-R6 + R13. Add +3V3 and +5V
    PWR_FLAGs to give those rails an ERC driver. net_contract now passes; the
    controller section has no unconnected/undriven ERC errors.
    [reflow.kicad_sch]
2026-06-29 hardware: assign footprints, ERC clean, finalize electrical calcs
    - Q2/Q3 (BS170): new energy_system:TO-92_Inline_GDS footprint with NUMERIC
    pads 1/2/3 placed at the BS170 physical legs (left=Drain, mid=Gate,
    right=Source per ON Semi BS170/D Rev2). Numeric pads are required because
    the stock Q_NMOS_GDS symbol numbers its pins 1/2/3; pcb_build.py and KiCad
    both bind pad-name to pin-number, so G/D/S-named pads would get no net.
    - Q1 (IRFS4710): switch to plain numeric TO-220-3_Vertical_LaserPads (the
    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
    [reflow.kicad_sch]
2026-06-29 hw(safety): resolve gate PWM-input net by topology in boot-safe check
    The check script was looking up the PWM-input net by the literal label
    "HEATER_PWM", which broke after GPIO25 and HEATER_PWM were merged onto
    one net (KiCad picks "GPIO25" as the primary name in the export).
    Fix: identify the PWM-input net by pin membership — the net containing
    R2 pin 1 (source side of the series gate resistor into Q2.G) — using
    the existing node_net() helper. All boot-safety assertions are unchanged;
    only the net resolution is now alias-robust.
    Verified: exit 0 on the correct schematic; exit 1 on forged netlists
    with (a) R6 removed and (b) PWM shorted directly to Q1.G.
    [check_gate_boot_safe.py]
2026-06-29 hw(buck): swap U2 to LM2575-ADJ with 5.03V feedback divider (R7 3K09 / R8 1K00)
    The DTU component shop stocks the adjustable LM2575, not the fixed LM2576-5.0.
    Swap U2 to LM2575BT-ADJ (same 5-pin TO-220 pinout/footprint) and add an R7/R8
    feedback divider into FB: Vout = 1.23*(1+3090/1000) = 5.03 V. Also fold the
    post-placement footprint finalization (5-pin laser pads, GDS variants, real
    toroid, fuse holder) and the unused-pin no_connect markers into build_schematic
    so it regenerates the finalized schematic faithfully. ERC=0, pad-nets and
    boot-safety still pass.
    [reflow.kicad_sch]
2026-06-29 hardware: BOM generated and cross-checked against DTU component shop
    Add check_bom_against_shop.py: reads board-soldered parts from the netlist
    (excludes A1/J3/J4 modules + F1 fuse holder), normalises each value (µ/u, Ω/R,
    k/K, E96 codes, cap/diode formats) and asserts a Part_Number/Value match in
    dtu_component_shop(1).csv. Exit 0 = all resolve.
    Snap the parts that only differed by value-string formatting to shop stock:
    D3 24V-rail TVS -> P6KE24P (24V standoff, ~33V clamp < 35V caps), D4 drain TVS
    -> 1.5KE36A (36V standoff > 24V rail, ~52V clamp << Q1 100V Vds), J1/J2 ->
    2 pol skrueterminal, SW1 -> Rotary 1x12 EYE, SW2 -> Pushbutton, D1 -> LED 5MM
    GRØN. All 31 board parts now resolve.
    A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
    [reflow.kicad_sch]
2026-06-29 hw(erc): restore C6 labels to script-computed pin endpoints; ERC back to 0
    The schematic was re-saved by KiCad (version stamp 20250114 → 20260306),
    which drifted the C6 +3V3 and GND net labels +0.064 mm in X and -0.114 mm
    in Y off the wire stub endpoints, leaving both labels dangling and both C6
    pins unconnected (4 ERC errors).
    Regenerated from build_schematic.py — no script changes needed; the script
    already computed the correct coincident coordinates for C6 (same as C5).
    All gates pass: ERC 0 errors, verify_pad_nets PASS, check_gate_boot_safe
    exit 0, net_contract exit 0, check_bom_against_shop exit 0.
    C6.1 → /+3V3 (J4.VCC/A1.3V3); C6.2 → /GND.
    [reflow.kicad_sch]
2026-06-29 hardware: build board, zone the layout, add high-current pours
    Build the single-sided B.Cu board from the final schematic and place all 35
    footprints into three zones inside the 104x104 mm outline: UI + the analog
    MAX31855 header along the top edge, the ESP32 controller in the centre, and the
    power corner (24V input, both regulators, buck passives, FB divider, heater
    MOSFET + gate drive, screw terminals + fuse) bottom-left - keeping the analog
    header far from the heater MOSFET.
    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
    [reflow.kicad_pcb]
2026-06-29 hardware: two-stage route (165 B.Cu tracks + 86 F.Cu jumper segs); 4 connections need manual finish
    [reflow-F_Cu.dxf, reflow.kicad_pcb]
2026-06-29 hardware: close +3V3 on B.Cu; +24V/HEATER_RET need wire bridges
    Route A1.30 (/+3V3) to the +3V3 net with a 6-segment B.Cu track down the
    clear lane between the ESP module pin column and the buck input, landing on
    the existing +3V3 copper. Refill zones. DRC: 0 copper-rule violations, +3V3
    connected.
    The two high-current crossings (+24V buck-input rail to its pour/F1.2, and
    HEATER_RET upper pads to the lower pour island) cannot be closed on the
    single-sided B.Cu copper: exhaustive search finds no path at the 1.0 mm
    minimum track and no fillable pour neck down to 0.3 mm, because the
    buck/gate-drive band plus the full-width +12V track form a continuous
    clearance fence. They are left for a manua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
    [reflow-F_Cu.dxf, reflow.kicad_pcb]
2026-06-29 hardware: export SRM-20 mill production files and milling notes
    - B.Cu+Edge DXF (reflow.dxf), F.Cu+Edge DXF (reflow_top_cu.dxf already
    tracked), silk DXF (reflow_silk_top.dxf) via export_production.ps1
    - Mirrored B.Cu SVG (reflow_mill_bcu.svg) for mods CE / gerber2rml
    - Full Gerber set + Excellon drill in production/gerbers/
    - MILL_NOTES.md: three SRM-20 jobs, origin/Z-zero procedure, wide-pour
    caveat, and hand-finish items (86 F.Cu jumpers + 2x 13A wire bridges)
    [reflow-B_Cu.gbl, reflow-B_Mask.gbs, reflow-Edge_Cuts.gm1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]
2026-06-29 Add 3D enclosure design spec
2026-06-29 Add 3D enclosure implementation plan
2026-06-29 3d: parametric plate frame with ceramic-standoff bosses and air gap
    [plate_frame.stl]
2026-06-29 3d: electronics box with PCB bosses, vents, terminal openings, insert bosses
    [box.stl]
2026-06-29 3d: correct enclosure to 3-part top-panel design (box fits 104x104 board on posts; panel=lid)
2026-06-29 3d: electronics box sized for the board, corner support posts, vents, terminal openings, top-rim inserts
    [box.stl]
2026-06-29 3d: top control panel with cut-outs from placement.json, mates the box rim
    [panel.stl]
2026-06-29 refactor(panel): read vent anchors from placement.json; assert J4 rotation
    - Vent slot centres now derived from placement.json U2/U3 entries via
    _affine(), replacing hardcoded literals 42.5 / 58.4. Fallback defaults
    preserved so build never crashes if a key is absent.
    - Assert added before OLED boolean that J4 rotation == 0; message explains
    swap needed for 90°/270° orientation.
    Verified: manifold_ok True, fits_bed True, cut_centers unchanged,
    MATES True, vent_cx=-1.55 vent_cy=-21.7 (from JSON U2/U3).
2026-06-29 3d: assembly interference check, STL exports, enclosure.blend, and build README
    [enclosure.blend, panel.stl, plate_frame.stl]
2026-06-29 fix(panel): reposition OLED window fully inside panel; add outline guard
    The OLED window was centred on J4's board coordinate (-46.2, -42.4),
    placing its left edge at -59.2 mm — 2.7 mm past the 56.5 mm panel
    half-width, creating an open-sided notch.
    The SSD1306 module is wired to J4 via cable, so the window position is
    independent of the J4 footprint. Move window to (-25.0, 20.0) — upper-
    left quadrant — with all four edges well within ±53.5 mm (≥15.5 mm
    margin on every side) and ≥12.8 mm from the nearest screw boss.
    Add _assert_inside_outline() that checks every cut (control holes, OLED
    window, screw holes) stays within the panel outline before the booleans
    run. Guard correctly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
    [panel.stl]
2026-06-29 3d: refresh enclosure.blend and STL exports after OLED window fix
    [enclosure.blend, panel.stl]
2026-06-29 chore: ignore KiCad autoplace/routing scratch and stray blend
2026-06-30 3d: refit enclosure to re-placed PCB; import board GLB into assembled view; raise box to 40mm for vertical TO-220s
    [box.stl, enclosure.blend, panel.stl]
2026-06-30 3d: fix board centering in assembly via origin_set (was offset +60mm in X)
    [enclosure.blend]
2026-06-30 hardware: update board with re-placed footprints (user re-placement)
    [reflow.kicad_pcb]
2026-06-30 Add firmware design spec (ESP-IDF/C, PID, NVS profiles, WiFi dashboard)
2026-06-30 firmware: PlatformIO scaffold with native Unity test env
    [partitions.csv]
2026-06-30 firmware/core: PID with anti-windup and derivative-on-measurement
2026-06-30 safety(pid): guard dt=0 derivative and add NaN/Inf output clamp
    - Skip derivative (and avoid divide-by-zero) when dt_s <= 0
    - After computing output, force to out_min if isnan/isinf — fail-safe
    - Two new regression tests: test_dt_zero_is_finite_and_safe, test_output_never_nan
2026-06-30 design: add 5V cooling fan in split-range PID loop (FAN_PWM=GPIO13); core/actuator task + board-revision note
2026-06-30 firmware/core: safety watchdog (overtemp/runaway/tc-fault/stall)
2026-06-30 firmware/core: split-range actuator (heater/fan deadband mapping)
2026-06-30 firmware: document FAN_PWM=GPIO13 in README pin map (match net contract)
